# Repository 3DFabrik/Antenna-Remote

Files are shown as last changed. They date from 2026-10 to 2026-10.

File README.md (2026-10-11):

# Antenna Remote

Ein Antennenumschalter für bis zu acht Antennen auf einem ESP32. Er wählt die Antenne nach der Frequenz des Transceivers (Automatik) oder von Hand, zeigt alles auf einem Touch-Display und lässt sich über WLAN, Bluetooth und eine Weboberfläche bedienen. [SDROxide](https://github.com/3DFabrik/sdroxide) kann ihm die Frequenz direkt über WLAN schicken. Die Firmware ist eine Weiterentwicklung der Antenna Remote II.

Gedacht ist die Einheit für die Fernumschalter von [Amplitec](https://www.amplitec.hu/r_sw_3000_4_way_eng.html) (SW:3000) mit vier, sechs oder acht Wegen. Sie schaltet positiv und passt damit zu Umschaltern mit gemeinsamer Masse. Die Anzahl der Antennen (bis zu acht) wird in den Einstellungen gewählt.

Die Firmware-Version steht oben in der Weboberfläche. Ein Release-Build trägt den Tag als Version, ein lokaler Build seine Bauzeit.

## Was dazugehört

- **ESP32** Dev Module, 4 MB Flash. Die Partition `min_spiffs` hält zwei Programme vor, damit ein Update über WLAN möglich ist.
- **Touch-Display** ST7789, 320 × 240, quer eingebaut, mit Touch-Controller.
- **Schieberegister** 74HC164 für die Relais der acht Antennen. Genau ein Ausgang ist aktiv.
- **ICOM-Anschluss** (optional): CI-V an `Serial2` (19200 Baud, GPIO 16 und 17). Der Umschalter liest damit die Frequenz und schaltet auf Wunsch den internen Tuner des Transceivers.

| Funktion | GPIO |
| --- | --- |
| Display MOSI, SCLK, MISO | 4, 18, 19 |
| Display CS, DC, RST | 15, 2, 23 |
| Touch CS | 21 |
| Schieberegister CLR, A/B, CLK | 25, 26, 27 |
| Relais externer Tuner, Relais Tune-Anforderung | 33, 32 |

Die Display-Pins stehen in `libraries/TFT_eSPI/User_Setup.h`. Beim ersten Start fragt das Display nach der Touch-Kalibrierung.

## Bedienung am Gerät

- **Seite 1** zeigt Frequenz, Band und die Antennenliste. `AUTOMATIC MODE` schaltet zwischen Automatik und Handbetrieb um. Zwischen diesem Schalter und `MISC` stehen zwei Symbole für die Verbindung: im Bluetooth-Modus das Bluetooth-Zeichen (grün, solange ein Client verbunden ist), im WLAN-Modus die Signalstärke (drei Bögen) und ein Bildschirm-Symbol, das grün wird, solange SDROxide verbunden ist. Die Weboberfläche zeigt dasselbe oben rechts. Im Handbetrieb wählen UP und DN die Antenne. Hält man `ST` eine Sekunde, wird die aktuelle Antenne für das aktuelle Band gespeichert. Im Automatikmodus heißt dieselbe Taste `TU` und startet den Tuner, siehe unten.
- **Seite 2** (`MISC`) zeigt die Verbindung: Modus, SSID, Status, IP, Signal, ob SDROxide verbunden ist, Antenne und Automatik. Hier wird auch der Verbindungsmodus eingestellt.

## Tuner

In den Einstellungen der Weboberfläche lässt sich pro Antenne das Häkchen `External Tuner` setzen. Ist es für die gewählte Antenne gesetzt, schaltet der Umschalter das erste Relais (GPIO 33) für den externen Tuner. Damit ist der Antennentuner des Transceivers abgeschaltet.

Die Taste `TU` (Display, Automatikmodus) und `TUNING` (Weboberfläche) sind nur dann aktiv, wenn die gewählte Antenne diese Markierung hat. Sonst sind sie grau. Ein Druck löst über das zweite Relais (GPIO 32) für genau fünf Sekunden die Tune-Anforderung aus, auch wenn der Finger auf der Taste bleibt. Der Transceiver sendet dann ein Signal mit geringer Leistung, auf das sich der externe Tuner abstimmt. Während der Anforderung ist die Taste rot. Ein erneuter Druck bricht sie ab, ebenso ein Wechsel der Antenne oder des Modus.

## Verbindung: Bluetooth oder WLAN

Der Umschalter läuft entweder mit Bluetooth oder mit WLAN, nie mit beidem. Auf Seite 2 wechselt `BT -> WLAN` (bzw. `WLAN -> BT`) den Modus. Das Gerät startet danach neu, und der Wechsel muss einmal bestätigt werden.

**WLAN einrichten:** Im WLAN-Modus öffnet `WLAN setup` eine Netzliste mit Scan. Das Netz antippen und das Passwort mit der Bildschirmtastatur eingeben (`Show` zeigt es im Klartext). Versteckte Netze gibt es über `HIDDEN`. Der Status auf Seite 2 nennt Fehler im Klartext, zum Beispiel `SSID not found` oder `Wrong password?`. Das Passwort liegt getrennt von der Konfiguration im Flash und wird nie ausgegeben.

Über die serielle Konsole (115200 Baud) geht es auch:

| Befehl | Wirkung |
| --- | --- |
| `<WIFI,ssid,passwort>` | speichert das WLAN (das Passwort darf Kommas enthalten) |
| `<NETMODE,wifi>` oder `<NETMODE,bt>` | Modus wählen, danach Neustart |
| `<WIFISTATUS>` | Modus, SSID, Status, IP und Signal |

## Weboberfläche

Im WLAN-Modus ist der Umschalter unter `http://<IP-Adresse>/` erreichbar. Die Seite passt sich der Fenstergröße an.

- **Main:** Frequenz in einer LCD-Anzeige, eine Taste pro Antenne, `AUTOMATIC`, `INT TUNER` und `TUNING`.
- **Settings:** Antennenanzahl, Namen, externer Tuner pro Antenne, Zuordnung der Bänder 160 bis 4 m und ICOM-Typ. `Reboot` startet neu. `Reset` stellt die Werkseinstellungen her, behält aber den WLAN-Modus.
- **Update:** Firmware über den Browser einspielen, siehe unten.

Es gibt kein Passwort, der Umschalter gehört ins Heimnetz. Änderungen nimmt er nur per POST mit einem eigenen Header an, damit eine fremde Webseite ihn nicht schalten kann.

## SDROxide

In SDROxide unter Settings → Radio den Haken `Use Antenna Remote` setzen und unter Settings → Servers die IP-Adresse des Umschalters eintragen. SDROxide zeigt dort, ob die Verbindung steht, und schickt die Frequenz des Radios. Die Automatik des Umschalters wählt danach die Antenne.

Das Protokoll ist Text über TCP, Port 4540, eine Zeile pro Befehl. Es kommt immer nur ein Client zum Zug. Ein weiterer wird abgewiesen, solange der erste mindestens einmal in zwei Sekunden fragt. Schweigt er länger, übernimmt ein neuer Client die Verbindung, nach fünf Sekunden Stille wird er getrennt.

| Anfrage | Antwort |
| --- | --- |
| `v` | `AntennaRemote 1` und `RPRT 0` |
| `F <Hz>` | `RPRT 0` (Frequenz des Radios in Hertz) |
| `s` | `ant=<1-8> auto=<0\|1> band=<m> n=<Anzahl> name=<Text>` und `RPRT 0` |
| `M <0\|1>` | `RPRT 0` (Automatik aus oder ein, ab Version 1.1.0) |
| `A <n>` | `RPRT 0` (Antenne `n` wählen und auf Handbetrieb schalten, ab Version 1.2.0) |

Alles andere beantwortet der Umschalter mit `RPRT -1`. SDROxide zeigt die aktive Antenne, einen Schalter für die Automatik und im Handbetrieb Tasten zum Weiterschalten in der Kopfleiste (Box `ANT SW`).

## Windows-Programm

Das Windows-Programm Antenna Remote V2 läuft weiter über Bluetooth oder die serielle Schnittstelle, auch mit OmniRig. Die Befehle in der Form `<ANTNUMBER,3,0>` sind unverändert. Antennen und Bandzuordnung lassen sich jetzt aber auch in der Weboberfläche pflegen.

## Firmware einspielen

Die Release-Dateien stehen unter *Releases*:

- `Antenna-Remote_ota.bin` ist das Programm für das **Update im Browser** (Reiter *Update*) oder per `curl`:
  `curl -H "X-AR: 1" -F "firmware=@Antenna-Remote_ota.bin" http://<IP>/update`
  Das Update läuft nur im WLAN-Modus. Vorher sollte nicht gesendet werden, denn der Umschalter startet danach neu.
  Die Weboberfläche prüft über den Browser (höchstens einmal am Tag) auf GitHub, ob es eine neuere Version gibt, und zeigt dann oben einen Hinweis mit Link zum Reiter *Update*. Dort führt ein Link zu den Dateien des Releases.
- `Antenna-Remote.bin` ist das Abbild für **USB**. Es wird ab Adresse 0 geschrieben:
  `esptool.py --chip esp32 write_flash 0x0 Antenna-Remote.bin`

## Selbst bauen

Arduino IDE oder `arduino-cli` mit dem Board-Paket `esp32:esp32` in Version **2.0.17**. Die mitgelieferte TFT_eSPI passt zu dieser Version, die Core-Reihe 3 baut sie nicht.

```
arduino-cli compile --fqbn esp32:esp32:esp32:PartitionScheme=min_spiffs --libraries libraries .
```

Die Bibliothek `libraries/TFT_eSPI` enthält die Pinbelegung des Displays. Beim Bauen in der Arduino IDE den Ordner `libraries` als Sketchbook-Bibliothek eintragen oder die Bibliothek dorthin kopieren.

## Release über GitHub

Ein Tag `v…` baut die Firmware auf GitHub und legt ein Release mit beiden Dateien an:

```
git tag v1.0.0
git push origin v1.0.0
```

Alternativ startet man *Actions → Release → Run workflow* und gibt die Version ein. Der Ablauf steht in `.github/workflows/release.yml`.

## Hardware

Die Platine liegt unter `hardware/` (KiCad):

- `kicad/` Projekt (Schaltplan, Leiterplatte), Stückliste und Netzliste
- `production/` Gerber- und Bohrdateien, `BOM.xlsx`
- `docs/` Schaltplan als PDF
- `3d/` STEP-Modell

**Bekannte Fehler:**

- Der Buzzer (BZ1) ist im Schaltplan nicht richtig angeschlossen, der ESP32-Pin muss getauscht werden. Die Firmware steuert noch keinen Buzzer an.
- Der Buzzer sitzt auf der Leiterplatte zu nah am Rand und muss etwas weiter nach innen.

## Lizenz

MIT, siehe `LICENSE`. Die Bibliothek TFT_eSPI unter `libraries/TFT_eSPI` hat ihre eigene Lizenz (`license.txt`).

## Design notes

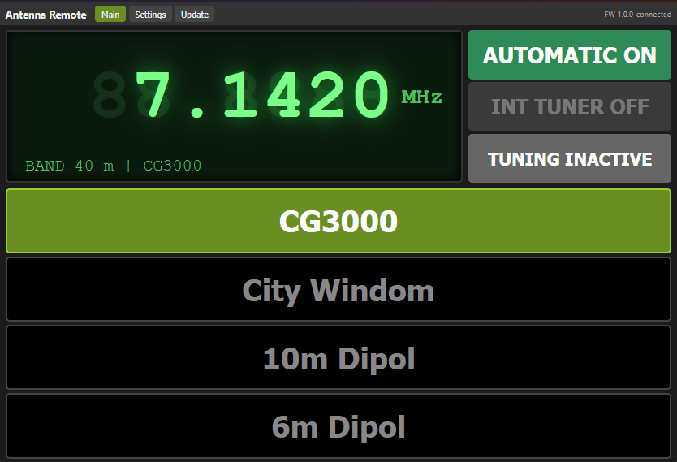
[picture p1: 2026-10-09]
pictures/Web Screenshot.png

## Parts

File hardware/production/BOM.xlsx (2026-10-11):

Source: | U:\Hobby\Funkerei\Antennenumschalter\PCB\Antennenumschalter_ESP32 - V3\Antennenumschalter_ESP32.kicad_sch
Date: | 2023-11-11 14:19
Tool: | Eeschema 7.0.7
Generator: | C:\Program Files\KiCad\7.0\bin\scripting\plugins/bom_csv_grouped_by_value.py
Component Count: | 38
Collated Components:
Item | Qty | Reference(s) | Value | LibPart | Footprint | Datasheet | DNP | Availability | Check_prices | Description | MANUFACTURER | MAXIMUM_PACKAGE_HEIGHT | MF | MP | PARTREV | Package | Price | Purchase-URL | SNAPEDA_PN | STANDARD | Sim.Device | Sim.Pins | SnapEDA_Link
1 | 1 | BZ1 | PB12N23MPW03AQ | Device:Buzzer | Buzzer_Beeper:Buzzer_12x9.5RM7.6 | https://www.reichelt.de/index.html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
2 | 1 | C1 | 330n | Device:C_Polarized | Capacitor_THT:C_Rect_L4.6mm_W2.0mm_P2.50mm_MKS02_FKP02 | ~
3 | 11 | C2, C5, C6, C7, C8, C9, C10, C11, C12, C13, C14 | 22p | Device:C | Capacitor_THT:C_Disc_D5.0mm_W2.5mm_P2.50mm | ~
4 | 1 | C3 | 100n | Device:C | Capacitor_THT:C_Rect_L4.6mm_W2.0mm_P2.50mm_MKS02_FKP02 | ~
5 | 1 | C4 | 100yF/20V | Device:C_Polarized | Capacitor_THT:CP_Radial_D5.0mm_P2.50mm | ~
6 | 1 | D1 | 1N4001 | Device:D | Diode_THT:D_DO-41_SOD81_P3.81mm_Vertical_KathodeUp | ~ |  |  |  |  |  |  |  |  |  |  |  |  |  |  | D | 1=K 2=A
7 | 3 | D2, D3, D4 | 1N4148 | Diode:BA243 | Diode_THT:D_DO-35_SOD27_P7.62mm_Horizontal | https://www.reichelt.de/schalt-diode-100-v-150-ma-do-35-1n-4148-p1730.html?&nbc=1 |  |  |  |  |  |  |  |  |  |  |  |  |  |  | D | 1=K 2=A
8 | 1 | F1 | PTC FRX03060F 300mA | Device:Polyfuse | Fuse:Fuse_BelFuse_0ZRE0005FF_L8.3mm_W3.8mm | https://www.reichelt.de/index.html?ACTION=7&LA=3&OPEN=0&INDEX=0
9 | 1 | J1 | D-SUB BU 09US Female Antenna Switch | Connector:Conn_01x09_Socket | Connector_Dsub:DSUB-9_Female_Horizontal_P2.77x2.84mm_EdgePinOffset7.70mm_Housed_MountingHolesOffset9.12mm | https://www.reichelt.de/index.html?ACTION=446&LA=446&nbc=1&q=d-sub%20bu%2009us
10 | 1 | J3 | D-SUB ST 09US Male Ancillaries | Connector:Conn_01x09_Pin | Connector_Dsub:DSUB-9_Male_Horizontal_P2.77x2.84mm_EdgePinOffset7.70mm_Housed_MountingHolesOffset9.12mm | https://www.reichelt.de/index.html?ACTION=446&LA=446&nbc=1&q=d-sub%20%2009us
11 | 1 | J4 | DISPLAY | Connector:Conn_01x13_Pin | Connector_PinHeader_2.54mm:PinHeader_1x13_P2.54mm_Vertical | ~
12 | 2 | K1, K2 | CO 3570.1210.121 | Relay:DIPxx-1Axx-11x | Relay_THT:COMUS Reed-Relais 12 V DC, 10 W - 1 NO | https://www.reichelt.de/reed-relais-12-v-dc-10-w-1-no-co-3570-1210-121-p340168.html?&nbc=1
13 | 2 | Q1, Q2 | BC550 | Transistor_BJT:BC550 | Package_TO_SOT_THT:TO-92L_Inline_Wide | https://www.onsemi.com/pub/Collateral/BC550-D.pdf
14 | 2 | R1, R7 | 10K | Device:R | Resistor_THT:R_Axial_DIN0207_L6.3mm_D2.5mm_P10.16mm_Horizontal | ~
15 | 3 | R2, R3, R6 | 4K7 | Device:R | Resistor_THT:R_Axial_DIN0207_L6.3mm_D2.5mm_P10.16mm_Horizontal | ~
16 | 2 | R4, R5 | 100K | Device:R | Resistor_THT:R_Axial_DIN0207_L6.3mm_D2.5mm_P10.16mm_Horizontal | ~
17 | 1 | U1 | 74HC164 | 74xx:74HC164 | Package_DIP:DIP-14_W7.62mm_Socket | https://www.reichelt.de/schieberegister-8-bit-seriell-zu-parallel-2--6-v-dil-14-74hc-164-p3154.html?nbc=1
18 | 1 | U2 | LM7805_TO220 | Regulator_Linear:LM7805_TO220 | Package_TO_SOT_THT:TO-220-3_Vertical | https://www.onsemi.cn/PowerSolutions/document/MC7800-D.PDF
19 | 1 | U3 | ULN2803A | Transistor_Array:TBD62783A | Package_DIP:DIP-18_W7.62mm_Socket | https://www.reichelt.de/eight-darlington-arrays-dil-18-uln-2803a-p22085.html?&nbc=1
20 | 1 | U4 | ESP32-DEVKITC-32D | ESP32-DEVKITC-32D:ESP32-DEVKITC-32D | esp32_DevKitC:MODULE_ESP32-DEVKITC-32D |  |  | In Stock | https://www.snapeda.com/parts/ESP32-DEVKITC-32D/Espressif+Systems/view-part/?ref=eda | WiFi Development Tools (802.11) ESP32 General Development Kit, ESP32-WROOM-32D on the board | Espressif Systems | N/A | Espressif Systems | ESP32-DEVKITC-32D | V4 | None | None | https://www.snapeda.com/api/url_track_click_mouser/?unipart_id=2777395&manufacturer=Espressif Systems&part_name=ESP32-DEVKITC-32D&search_term=None | ESP32-DEVKITC-32D | Manufacturer Recommendations |  |  | https://www.snapeda.com/parts/ESP32-DEVKITC-32D/Espressif+Systems/view-part/?ref=snap

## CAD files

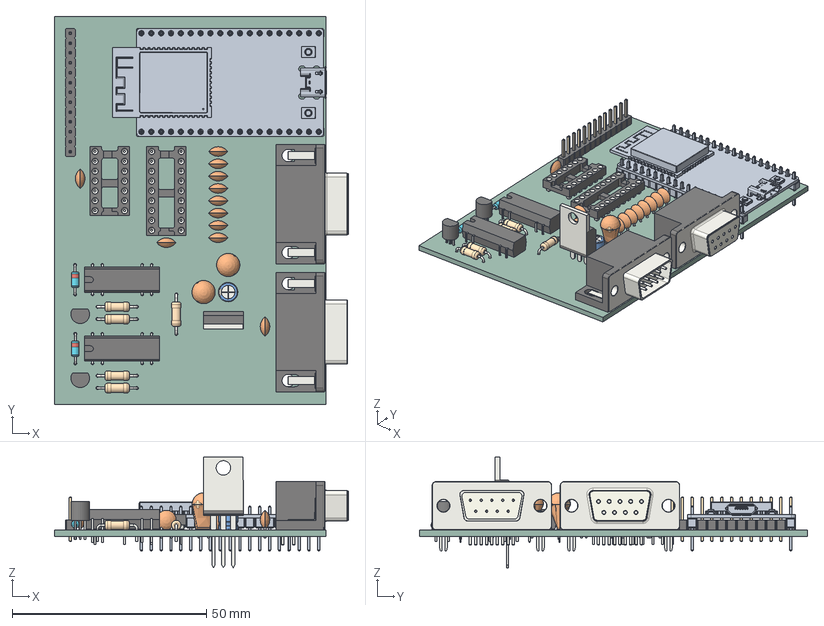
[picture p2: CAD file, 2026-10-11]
hardware/3d/Antenna-Remote.step
75.8 x 100.0 x 28.5 mm
Antenna-Remote PCB

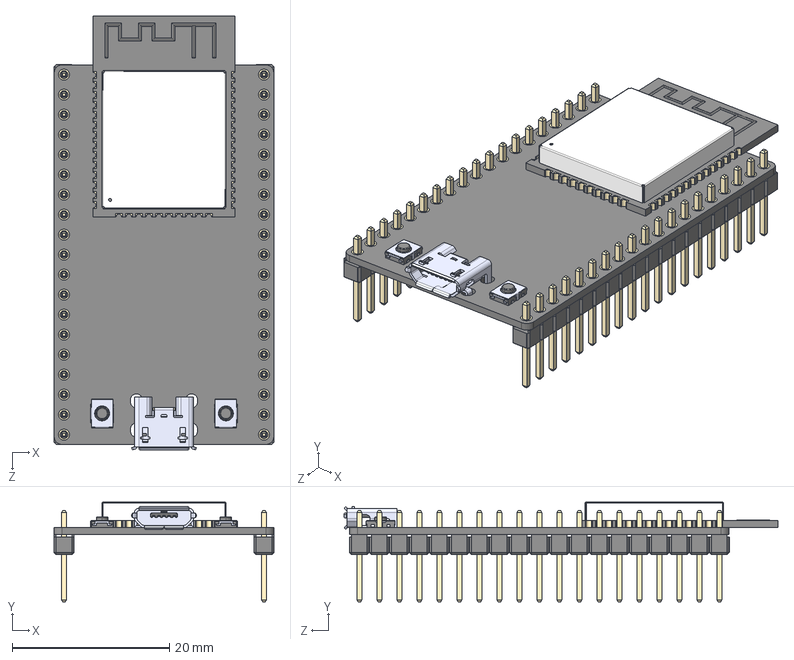
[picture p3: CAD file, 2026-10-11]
hardware/parts/esp32_DevKitC/ESP32-DEVKITC-32D.step
27.9 x 12.7 x 55.1 mm
board
header x 2
ESP32-WROOM-32D
micro usb
button x 2

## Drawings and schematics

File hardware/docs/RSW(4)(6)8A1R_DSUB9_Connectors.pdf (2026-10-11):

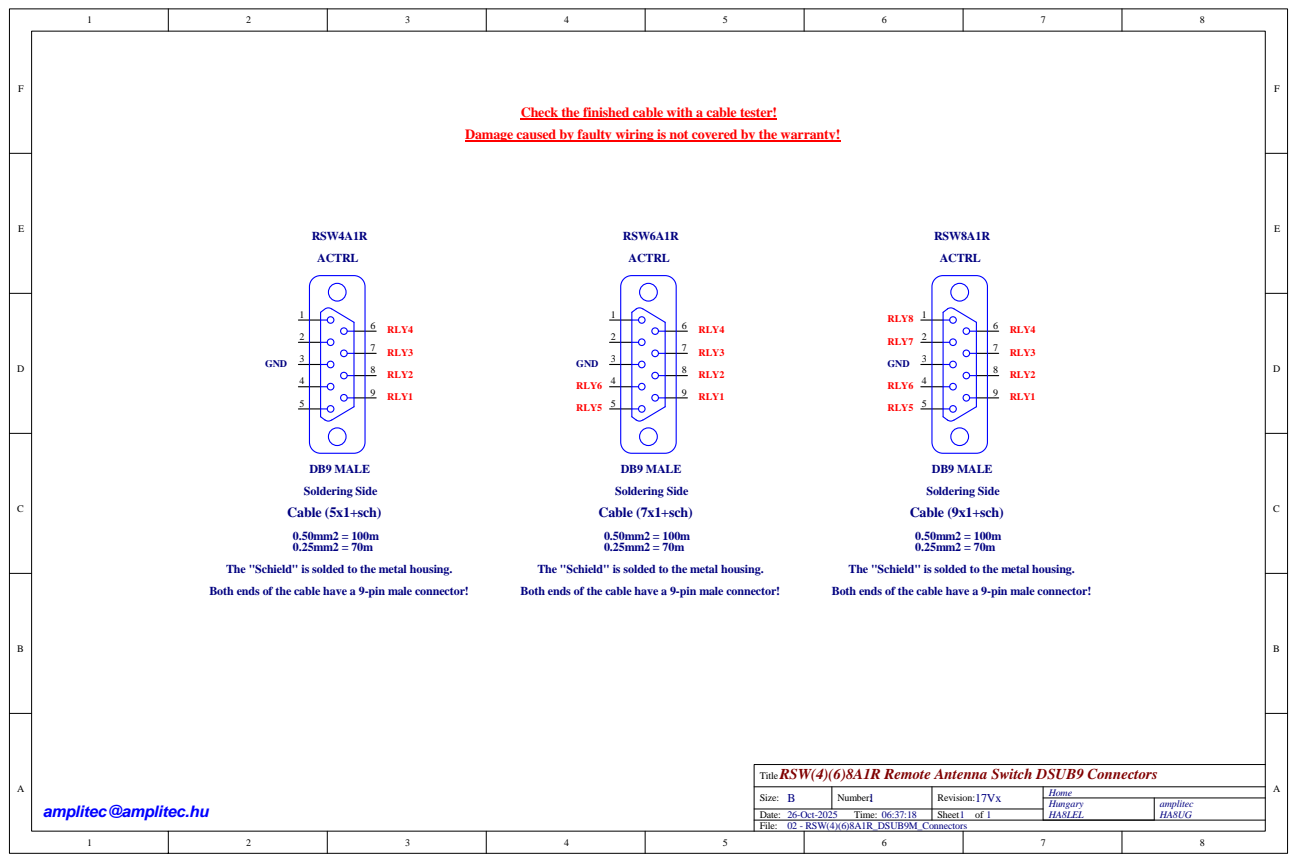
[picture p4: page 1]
Home Hungary HA8LEL; amplitec; 26-Oct-2025; Size:; Number:; Revision:; Time:; Sheet; ACTRL; DB9 MALE; RLY3; GND; RLY2; RLY1; RLY4; Soldering Side; RSW4A1R; Cable (5x1+sch); RLY5; RLY6; RSW6A1R; Cable (7x1+sch); RLY8; RLY7; RSW8A1R; Cable (9x1+sch); Both ends of the cable have a 9-pin male connector!

Check the finished cable with a cable tester!

Damage caused by faulty wiring is not covered by the warranty!

The "Schield" is solded to the metal housing.

RSW(4)(6)8A1R Remote Antenna Switch DSUB9 Connectors
Title
Date:
02 - RSW(4)(6)8A1R_DSUB9M_Connectors
File:

amplitec@amplitec.hu

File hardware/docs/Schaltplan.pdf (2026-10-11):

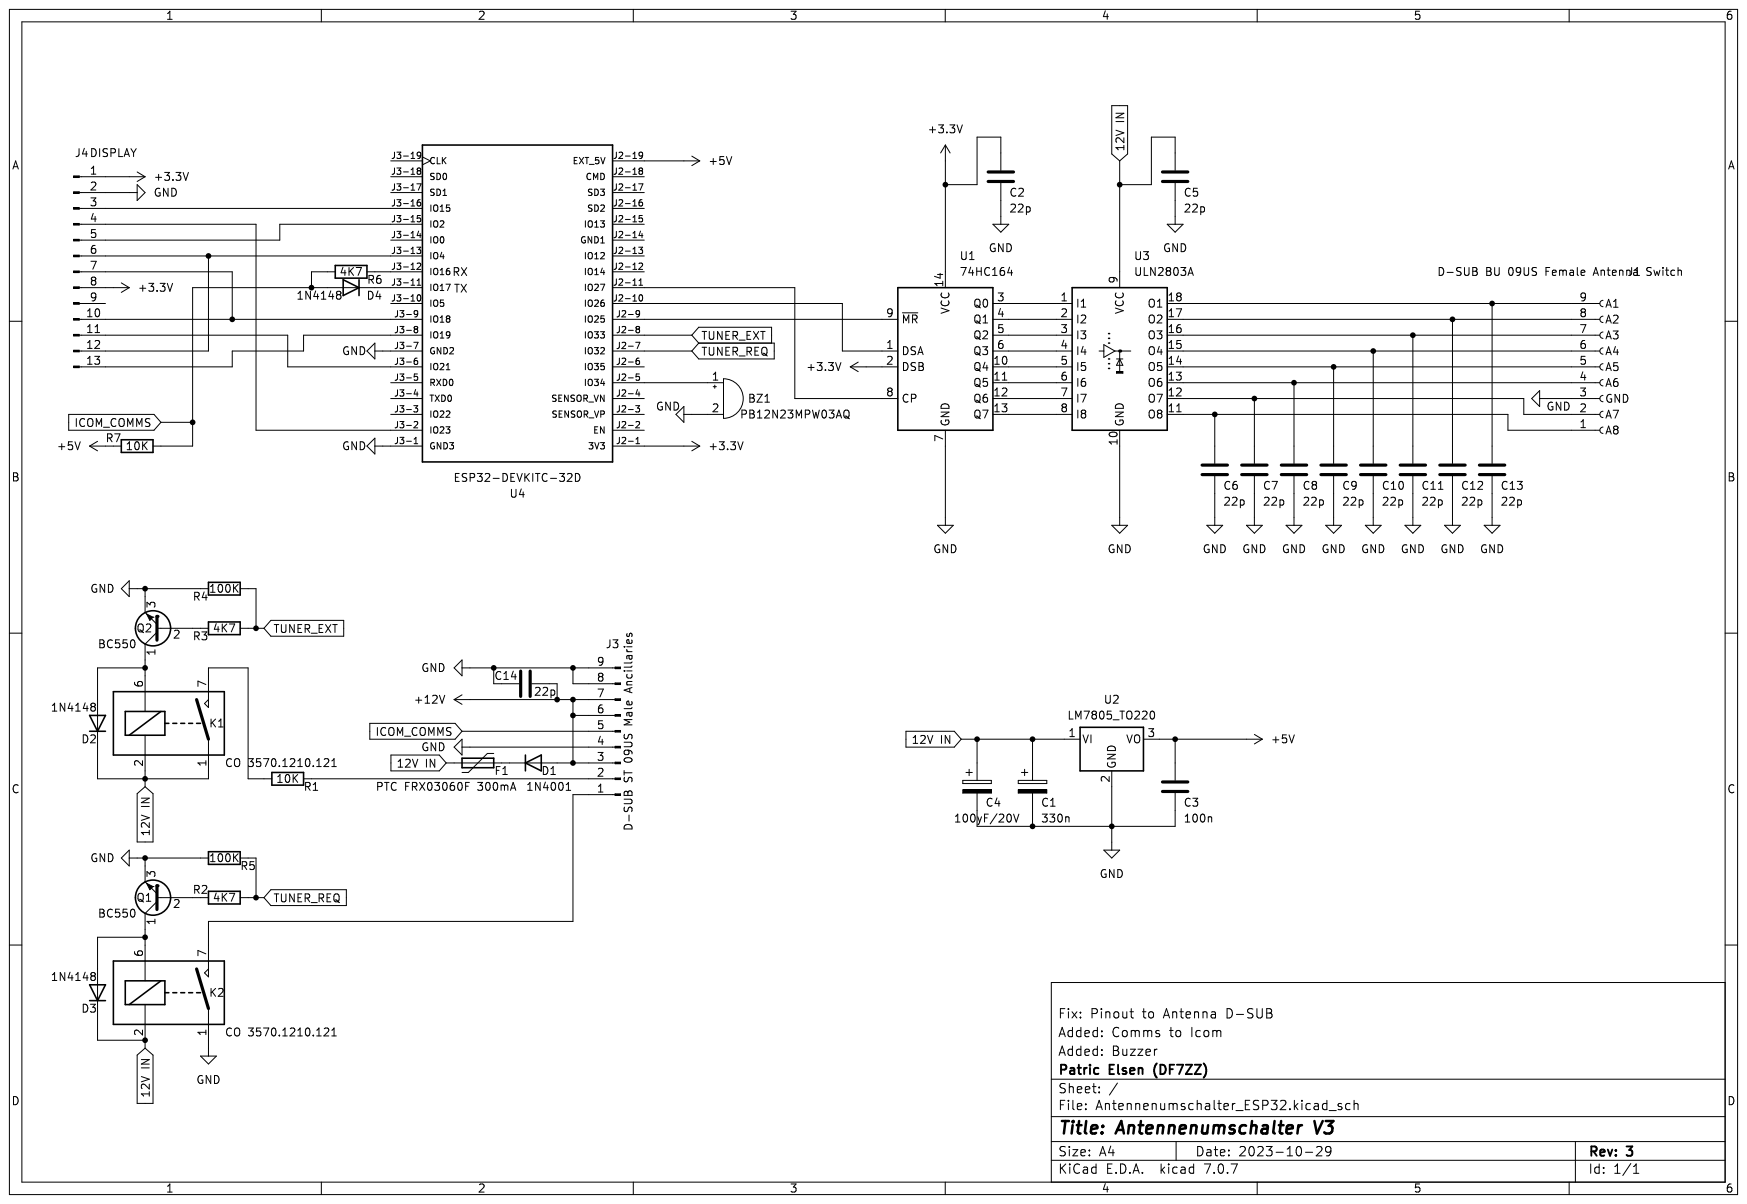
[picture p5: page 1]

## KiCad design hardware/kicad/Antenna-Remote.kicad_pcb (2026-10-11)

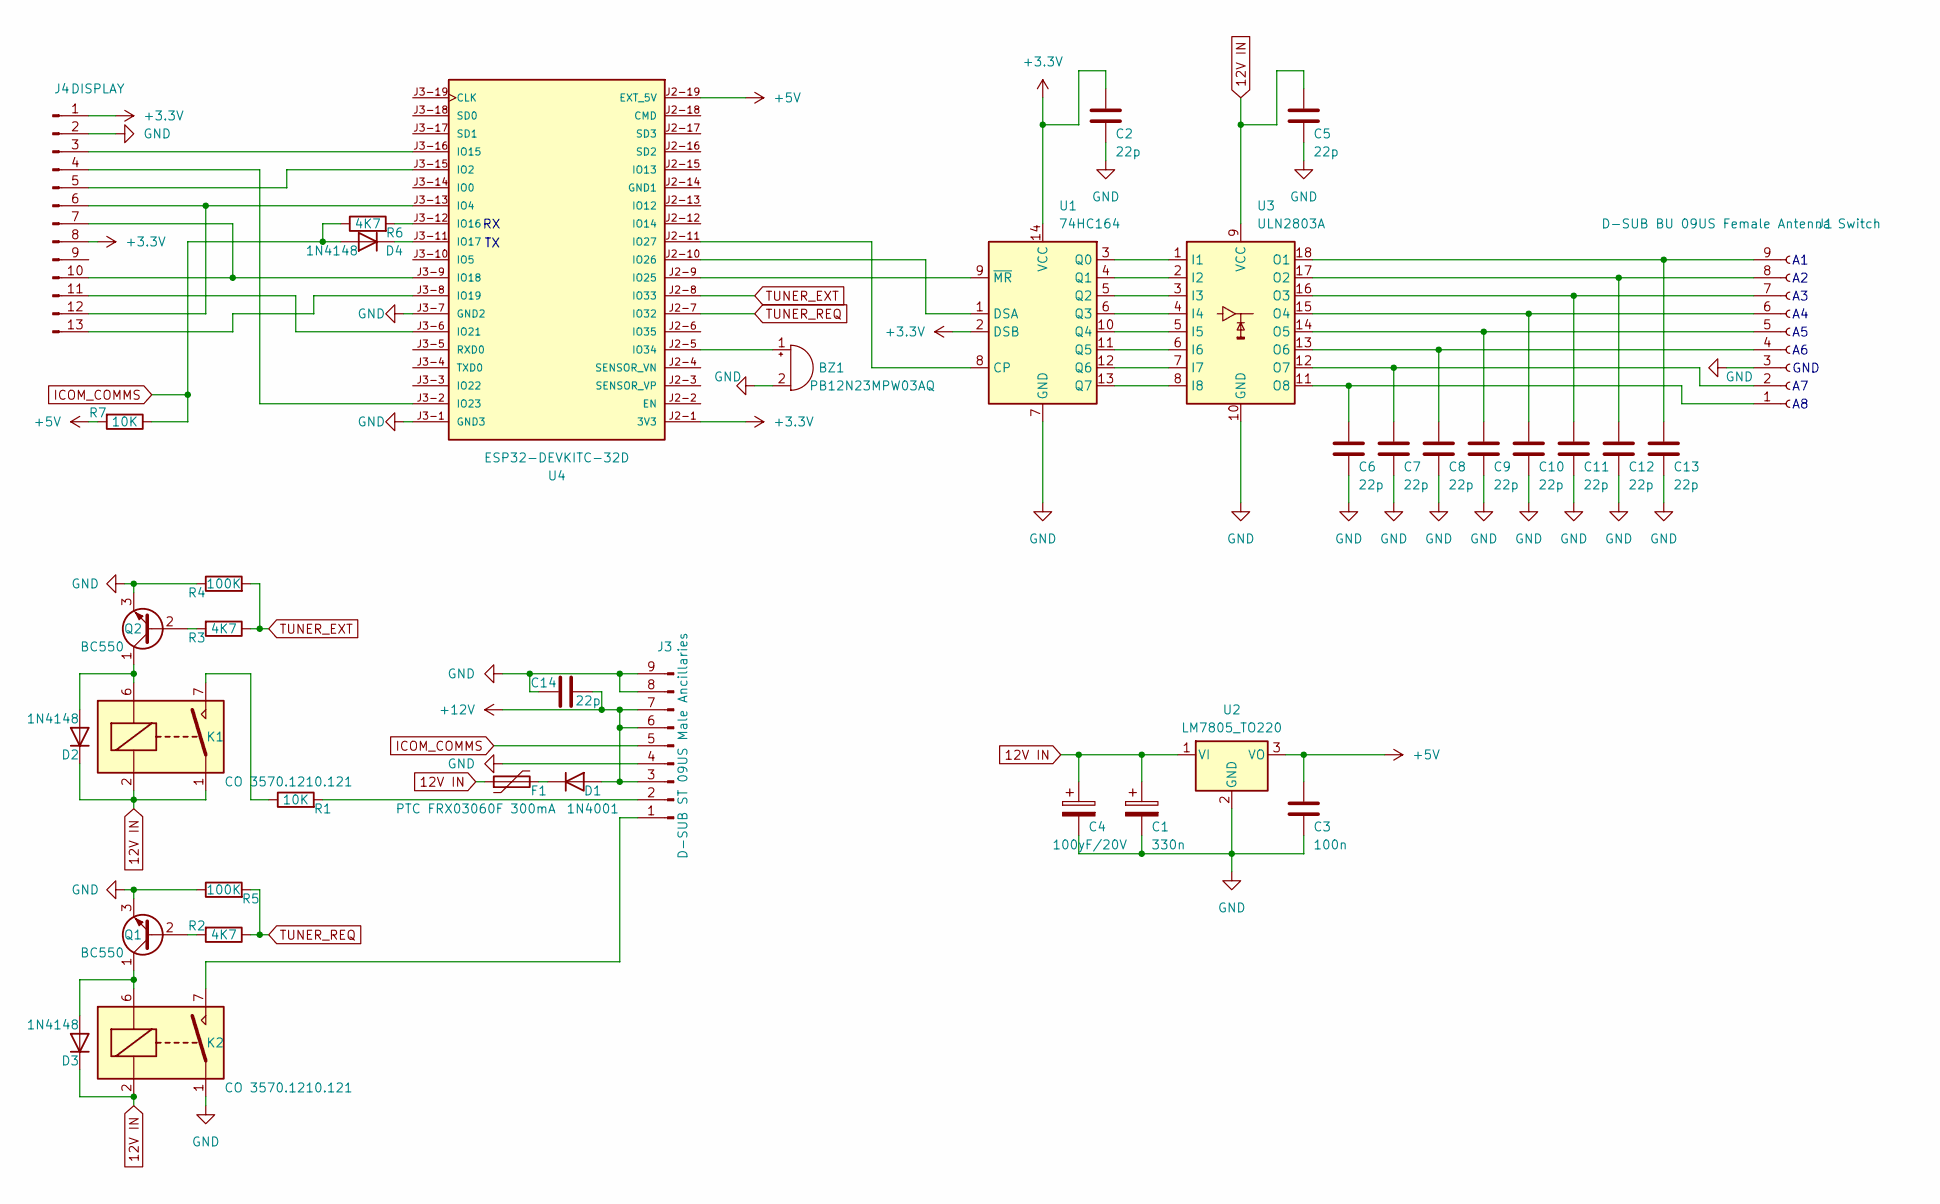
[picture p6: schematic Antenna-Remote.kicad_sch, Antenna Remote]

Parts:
BZ1: PB12N23MPW03AQ; Buzzer_12x9.5RM7.6
C1: 330n; C_Rect_L4.6mm_W2.0mm_P2.50mm_MKS02_FKP02
C2, C5, C6, C7, C8, C9, C10, C11, C12, C13, C14: 22p; C_Disc_D5.0mm_W2.5mm_P2.50mm
C3: 100n; C_Rect_L4.6mm_W2.0mm_P2.50mm_MKS02_FKP02
C4: 100yF/20V; CP_Radial_D5.0mm_P2.50mm
D1: 1N4001; D_DO-41_SOD81_P3.81mm_Vertical_KathodeUp
D2, D3, D4: 1N4148; D_DO-35_SOD27_P7.62mm_Horizontal
F1: PTC FRX03060F 300mA; Fuse_BelFuse_0ZRE0005FF_L8.3mm_W3.8mm
J1: D-SUB BU 09US Female Antenna Switch; DSUB-9_Female_Horizontal_P2.77x2.84mm_EdgePinOffset7.70mm_H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
J3: D-SUB ST 09US Male Ancillaries; DSUB-9_Male_Horizontal_P2.77x2.84mm_EdgePinOffset7.70mm_Hou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
J4: DISPLAY; PinHeader_1x13_P2.54mm_Vertical
K1, K2: CO 3570.1210.121; COMUS Reed-Relais 12 V DC, 10 W - 1 NO
Q1, Q2: BC550; TO-92L_Inline_Wide
R1, R7: 10K; R_Axial_DIN0207_L6.3mm_D2.5mm_P10.16mm_Horizontal
R2, R3, R6: 4K7; R_Axial_DIN0207_L6.3mm_D2.5mm_P10.16mm_Horizontal
R4, R5: 100K; R_Axial_DIN0207_L6.3mm_D2.5mm_P10.16mm_Horizontal
U1: 74HC164; DIP-14_W7.62mm_Socket
U2: LM7805_TO220; TO-220-3_Vertical
U3: ULN2803A; DIP-18_W7.62mm_Socket
U4: ESP32-DEVKITC-32D; MODULE_ESP32-DEVKITC-32D; PARTREV V4

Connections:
12V IN: C1.1, C4.1, C5.1, D2.1 (K), D3.1 (K), F1.1, K1.1, K1.2, K1.14, K2.2, U2.1 (VI), U3.9 (VCC)
+3.3V: C2.1, J4.1 (VCC), J4.8 (LED), U1.2 (DSB), U1.14 (VCC), U4.J2-1 (3V3)
+5V: C3.1, R7.2, U2.3 (VO), U4.J2-19 (EXT_5V)
+12V: C14.1, D1.2 (A), J3.3, J3.6, J3.7
GND: BZ1.2 (+), C1.2, C2.2, C3.2, C4.2, C5.2, C6.2, C7.2, C8.2, C9.2, C10.2, C11.2, C12.2, C13.2, C14.2, J1.3, J3.4, J3.8, J3.9, J4.2 (GND), K2.1, K2.14, Q1.3 (E), Q2.3 (E), R4.1, R5.1, U1.7 (GND), U2.2 (GND), U3.10 (GND), U4.J3-1 (GND3), U4.J3-7 (GND2)
ICOM_COMMS: D4.2 (A), J3.5, R6.1, R7.1
unnamed: BZ1.1 (-), U4.J2-5 (IO34)
unnamed: D1.1 (K), F1.2
unnamed: D2.2 (A), K1.6, Q2.1 (C)
unnamed: D3.2 (A), K2.6, Q1.1 (C)
unnamed: D4.1 (K), U4.J3-11 (IO17)
unnamed: C6.1, J1.1, U3.11 (O8)
unnamed: C7.1, J1.2, U3.12 (O7)
unnamed: C8.1, J1.4, U3.13 (O6)
unnamed: C9.1, J1.5, U3.14 (O5)
unnamed: C10.1, J1.6, U3.15 (O4)
unnamed: C11.1, J1.7, U3.16 (O3)
unnamed: C12.1, J1.8, U3.17 (O2)
unnamed: C13.1, J1.9, U3.18 (O1)
unnamed: J3.1, K2.7, K2.8
unnamed: J3.2, R1.2
unnamed: J4.3, U4.J3-16 (IO15)
unnamed: J4.4, U4.J3-2 (IO23)
unnamed: J4.5, U4.J3-15 (IO2)
unnamed: J4.7, J4.10, U4.J3-9 (IO18)
unnamed: J4.11, U4.J3-6 (IO21)
unnamed: J4.6, J4.12, U4.J3-13 (IO4)
unnamed: J4.13, U4.J3-8 (IO19)
unnamed: K1.7, K1.8, R1.1
unnamed: Q1.2 (B), R2.2
unnamed: Q2.2 (B), R3.2
unnamed: U1.8 (CP), U4.J2-11 (IO27)
unnamed: U1.1 (DSA), U4.J2-10 (IO26)
unnamed: U1.3 (Q0), U3.1 (I1)
unnamed: U1.4 (Q1), U3.2 (I2)
unnamed: U1.5 (Q2), U3.3 (I3)
unnamed: U1.6 (Q3), U3.4 (I4)
unnamed: U1.10 (Q4), U3.5 (I5)
unnamed: U1.11 (Q5), U3.6 (I6)
unnamed: U1.12 (Q6), U3.7 (I7)
unnamed: U1.13 (Q7), U3.8 (I8)
unnamed: U1.9 (~MR), U4.J2-9 (IO25)
unnamed: R6.2, U4.J3-12 (IO16)
TUNER_EXT: R3.1, R4.2, U4.J2-8 (IO33)
TUNER_REQ: R2.1, R5.2, U4.J2-7 (IO32)

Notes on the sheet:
GND

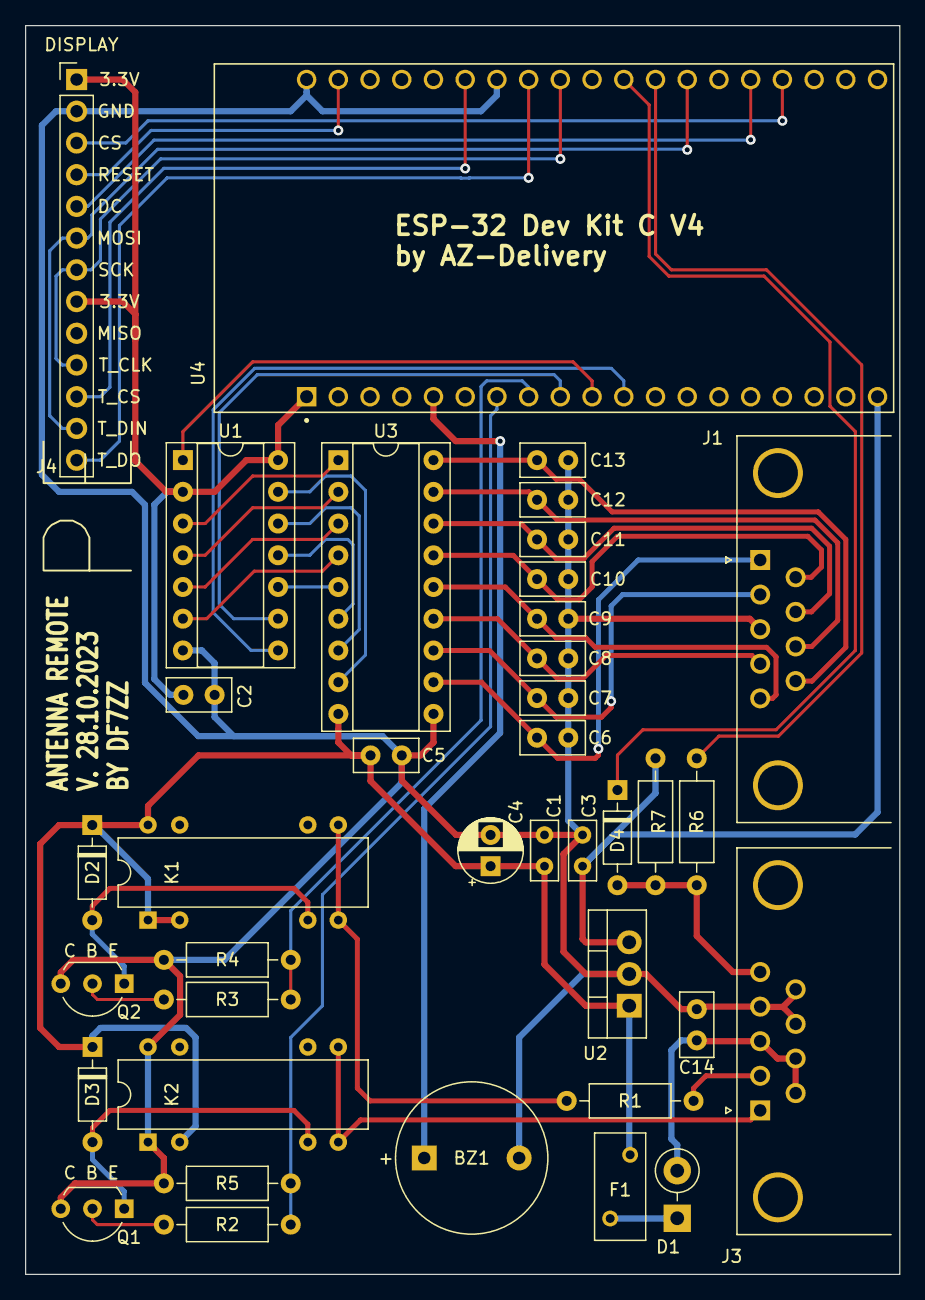
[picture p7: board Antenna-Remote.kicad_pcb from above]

Board: 2 copper layers, 70.0 x 100.0 mm, 38 parts (0 on the bottom side), 45 nets.

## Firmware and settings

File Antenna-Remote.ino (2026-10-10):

#include "FS.h"
#include "SPIFFS.h"
#include <WiFi.h>
#include <WiFiClient.h>
#include <WiFiServer.h>
#include <Preferences.h>
#include <Update.h>
Preferences netPrefs;  // WLAN credentials live here, not in config.txt, so "sendconfig" never reveals them
#include "BluetoothSerial.h"
BluetoothSerial SerialBT;
#include <WebServer.h>
#include "index.h"  //Web page header file
WebServer server(80);

#include <TFT_eSPI.h>  // Graphics and font library for ST7789 driver chip, be careful with updating as the fucking update will delete your pin-settings
#include <SPI.h>

#define TFT_GREY 0x5AEB  // New colours....
#define TFT_POPPY 0XD208
#define TFT_MINTGR 0XEFFF
#define TFT_NPBLUE 0X9EDB
#define TFT_UCLABLUE 0X43B3
#define TFT_DELFTBLUE 0X198A

int COLOR_BG = TFT_BLACK;
int COLOR_HIGHLIGHT = TFT_POPPY;

TFT_eSPI tft = TFT_eSPI();  // Invoke library
TFT_eSprite img = TFT_eSprite(&tft);

// Touch business
#define CALIBRATION_FILE "/TouchCalData1"
#define REPEAT_CAL false
#define KEY_X 295  // Center of key
#define AUTO_CX 98  // The AUTOMATIC button runs from the left edge to x = 196; the link icons sit between it and MISC
#define AUTO_W 196
#define NUM_KEYS 7
String b0_txt = "UP";
String b1_txt = "ST";
String b2_txt = "DN";
String b3_p1_txt = "MISC";
String b3_p2_txt = "BACK";
String b4_txt = "AUTOMATIC MODE OFF";
String b5_txt = "WLAN setup";
String b7_txt_off = "BT -> WLAN";  // shown while in Bluetooth mode: what the button switches to
String b7_txt_on = "WLAN -> BT";
int n_presscount_b1 = 0;
TFT_eSPI_Button key[NUM_KEYS];
unsigned long previousMillis = 0;  // will store last time touchscreen was checked
const long buttonIntervall = 100;

// Connection: either Bluetooth or WLAN, chosen at boot (config key b_wifi_on). Both radios at once do not fit.
bool b_wifi_on = false;  // true = WLAN mode, false = Bluetooth mode
bool bt_active = false;
String wifi_ssid = "";
String wifi_pass = "";
volatile int wifi_reason = 0;  // last disconnect reason from the WiFi stack, 0 = none
bool wifi_hold = false;        // true while the setup pages scan, so the retry timer stays out of the way
bool wifi_was_conn = false;
unsigned long wifi_last_try = 0;
bool servers_started = false;
unsigned long modeConfirmUntil = 0;
unsigned long hintUntil = 0;
String hintText = "";

// Remote protocol "AntennaRemote 1" for SDROxide: text lines on TCP, see crates/sdroxide-types/src/antremote.rs
const uint16_t RIG_PORT = 4540;
const unsigned long RIG_IDLE_MS = 5000;  // SDROxide polls once a second; silence this long means the client is gone
const unsigned long RIG_REPLACE_MS = 2000;  // a newcomer takes over from a client quiet for this long
WiFiServer rigServer(RIG_PORT);
WiFiClient rigClient;
String rigLine = "";
unsigned long rigLastSeen = 0;

// Firmware update over WLAN (POST /update, from the Update tab of the web page)
// Set by the release build (-DFW_VERSION="v1.2.3"); a local build shows its build time.
#ifndef FW_VERSION
#define FW_VERSION __DATE__ " " __TIME__
#endif
const char fwVersion[] = FW_VERSION;
bool otaBusy = false;  // from the first byte of an upload: the loop does nothing but serve it
bool otaBeginOk = false;
bool otaOk = false;
bool otaUploadStarted = false;
bool otaDenied = false;
unsigned long otaWifiLostAt = 0;
int otaPct = -1;
String otaErr = "";

// Setup pages (3 = network list, 4 = keyboard)
struct UiBtn {
  int16_t x, y, w, h;
  const char* label;
};
struct KbKey {
  int16_t x, y, w, h;
  char label[8];
  int16_t code;  // ASCII, or one of the KC_ values
};
const int KC_SHIFT = -1, KC_DEL = -2, KC_SYM = -3, KC_SHOW = -4, KC_CANCEL = -5, KC_OK = -6;
const int MAX_NETS = 16;
String netSsid[MAX_NETS];
int netRssi[MAX_NETS];
bool netOpen[MAX_NETS];
int netCount = 0;
int netTop = 0;
String pendingSsid = "";
String kbText = "";
int kbTarget = 1;  // 0 = SSID, 1 = password
int kbLayout = 0;  // 0 = letters, 2 = symbols
bool kbShift = false;
bool kbShow = false;
bool setupTouchWas = true;
String p2Last[8];

// Serial receive business
int icom_use = 0;        // sett to 1 in case you want tp use the icom CIV function of the TRX
byte TRX_address(0x98);  // HEX 0x70/112 = Icom IC-7000, 0x94/148 = Icom IC-7300, 0x98/152 = Icom IC-7610, store in SPIFFS as decimal value
const byte numChars = 128;  // a WLAN password can be 63 characters
char receivedChars[numChars];
char tempChars[numChars];         // temporary array for use when parsing
char SRX_TYPE[numChars] = { 0 };  // variables to hold the parsed data
float RX_FREQ = 0.0;
boolean newData = false;

// Misc Variabel
float QRG = 0;
int QRG_len_old = 0;
int BAND = 0;
int BAND_len_old = 0;
String ANT = "";
String ANT_OLD = "";
bool b_automatic = false;
bool b_booting = true;

//Define Bands:
int l160 = 1810;
int h160 = 2000;
int l80 = 3500;
int h80 = 3800;
int l60 = 5250;
int h60 = 5450;
int l40 = 7000;
int h40 = 7200;
int l30 = 10100;
int h30 = 10150;
int l20 = 14000;
int h20 = 14350;
int l17 = 18068;
int h17 = 18168;
int l15 = 21000;
int h15 = 21450;
int l12 = 24890;
int h12 = 24990;
int l10 = 28000;
int h10 = 29700;
int l6 = 50000;
int h6 = 52000;
int l4 = 70150;
int h4 = 70200;

//Define Antennas
String A1NAME = "1";  // Antenna names (Will be overwritten by what is found in SPIFFS config.txt)
String A2NAME = "2";  // ...
String A3NAME = "3";  // ..
String A4NAME = "4";  // .
String A5NAME = "5";
String A6NAME = "6";
String A7NAME = "7";
String A8NAME = "8";

String TUNEROFF = "0";  // Holds a decimal converted 8 bit binary which represents the use of the external tuner for each antenna
bool A1EXTT = 0;        // if bit is set this antenna uses an external tuner
bool A2EXTT = 0;        // ...
bool A3EXTT = 0;        // ..
bool A4EXTT = 0;        // .
bool A5EXTT = 0;
bool A6EXTT = 0;
bool A7EXTT = 0;
bool A8EXTT = 0;

//Define Antenna 2 Band
int a160m = 1;
int a80m = 1;
int a60m = 1;
int a40m = 1;
int a30m = 1;
int a20m = 1;
int a17m = 1;
int a15m = 1;
int a12m = 1;
int a10m = 1;
int a6m = 1;
int a4m = 1;

// The same settings as tables, for the web interface
String* antNames[8] = { &A1NAME, &A2NAME, &A3NAME, &A4NAME, &A5NAME, &A6NAME, &A7NAME, &A8NAME };
int* bandAnt[12] = { &a160m, &a80m, &a60m, &a40m, &a30m, &a20m, &a17m, &a15m, &a12m, &a10m, &a6m, &a4m };
const char* BAND_KEY[12] = { "a160m", "a80m", "a60m", "a40m", "a30m", "a20m", "a17m", "a15m", "a12m", "a10m", "a6m", "a4m" };
const int BAND_M[12] = { 160, 80, 60, 40, 30, 20, 17, 15, 12, 10, 6, 4 };

int antenna_selected = 1;  // the currently selected antenna number (1-n_ant_max)
int n_ant_max = 8;         // amount of antennas the switch can handle
int n_disp_page_old = 0;   // total amount of available display pages
int n_disp_page = 1;       // currently selected display page

// alive message
unsigned long aliveMillis = 0;
const long aliveintervall = 1000;  // intervall time in which a status-String gets send
String alivemsg = "";              // contains the alive message

// Scrolltext
unsigned long anttxtMillis = 0;
const long anttxtintervall = 35;
int textboxdiffy = 45;
int textboxstartfromtop = 10;
int scrolltarget = 0;
int scrollposact = 0;
//bool b_ant_col = true;

// Shift Register Pins
const int CLR_pin = 25;  // CLR-Pin of the 74HC164
const int AB_pin = 26;   // Input pin A or B of the 74HC164, remember to put 2nd open input to VCC
const int CLK_pin = 27;  // CLK-Pin of the 74HC164

// ICOM Tuner relais pins
const int TUNE_EXT_pin = 33;
const int TUNE_REQ_pin = 32;
bool tuning = false;
unsigned long tuneStart = 0;
const unsigned long TUNE_MS = 5000;  // a tune request is latched this long, then dropped
bool tuner = false;
int antenna_driven = 0;  // antenna the shift register currently holds

// ICOM coms variables
const byte startMarker = 0xFE;  // Indicates where the icom signal string starts
const byte endMarker = 0xFD;    // Indicates where the icom signal string ends
const int maxDataLength = 16;
byte receivedData[maxDataLength];  // Array for the recieved data bytes
int dataIndex = 0;                 // Pointer into the data array
bool newData2 = false;             // Set to true when a new data-array has been received
float SValue_raw = 0;
float SValue = 0;


//  ************************************************** Setup *******************************************************************************
void setup(void) {
  // Shift register pins:
  pinMode(AB_pin, OUTPUT);
  pinMode(CLK_pin, OUTPUT);
  pinMode(CLR_pin, OUTPUT);
  pinMode(TUNE_EXT_pin, OUTPUT);
  pinMode(TUNE_REQ_pin, OUTPUT);

  Serial.begin(115200);  // Serial console
  Serial2.begin(19200);  // ICOM CI-V
  Serial.println("Booting Sketch...");

  tft.init();
  tft.setRotation(3);
  tft.fillScreen(COLOR_BG);
  touch_calibrate();
  tft.setTextColor(TFT_GOLD);
  tft.setCursor(0, 0);
  tft.println("Booting");
  img.createSprite(260, 130);
  // Here we try to get some variables out of the software:
  tft.println("Reading Config values");
  readConfig();

  loadWifiCreds();
  if (b_wifi_on) {
    tft.println("Mode: WLAN");
    startWifi();  // connects in the background; the loop brings the servers up
  } else {
    tft.println("Mode: Bluetooth");
    SerialBT.begin("AntennaRemote");  //Name des ESP32
    bt_active = true;
    Serial.println("Bluetooth ready to connect");
  }

  tft.println("Selecting Antennas");
  sel_antenna();

  tft.println("Starting Display");
  tft_update();
  b_booting = false;
}

// *************************************************** LOOP ********************************************************************************
void loop(void) {

  if (otaBusy) {  // an update is coming in: nothing else may take heap, time or the relays
    if (WiFi.status() != WL_CONNECTED) {
      if (!otaWifiLostAt) otaWifiLostAt = millis();
      else if (millis() - otaWifiLostAt > 8000) ESP.restart();
    } else {
      otaWifiLostAt = 0;
    }
    server.handleClient();
    if (otaUploadStarted && !otaOk && otaErr.length()) {
      otaFailScreen(otaErr);
      delay(2000);
      ESP.restart();
    }
    yield();
    return;
  }


  recvWithStartEndMarkers();
  if (newData == true) {
    strcpy(tempChars, receivedChars);
    parseData();
    //showParsedData();
    newData = false;
  }

  if ((WiFi.status() == WL_CONNECTED) && (b_wifi_on)) {  // Only serve in case we are connected to the network
    server.handleClient();
    rigPoll();
  }
  wifiTick();

  if (tuning && millis() - tuneStart >= TUNE_MS) setTuning(false);

  if (TRX_address >= 1) geticomdata();
  if (newData2) {
    // Neue Daten verarbeiten oder anzeigen
    float QRGreaded = processReceivedData();
    if (QRGreaded > 0)  // new QRG
    {
      QRG = QRGreaded;
      tft_update();
    }
    // Zurücksetzen für den nächsten Durchlauf
    newData2 = false;
  }


  if (millis() - anttxtMillis >= anttxtintervall) {
    anttxtMillis = millis();
    if (n_disp_page == 1) { scrollAntennas(); }
  }

  //Touchscreen Business
  if (millis() - previousMillis >= (n_disp_page >= 3 ? 30UL : (unsigned long)buttonIntervall)) {  // the keyboard needs quicker polling than the buttons
    previousMillis = millis();
    uint16_t t_x = 0, t_y = 0;                // To store the touch coordinates
    bool pressed = tft.getTouch(&t_x, &t_y);  // Get current touch state and coordinates
    for (uint8_t b = 0; b < NUM_KEYS; b++) {  // Adjust press state of each key appropriately
      if (pressed && key[b].contains(t_x, t_y))
        key[b].press(true);  // tell the button it is pressed
      else
        key[b].press(false);  // tell the button it is NOT pressed
    }

    if (n_disp_page >= 3) { setupTouch(pressed, t_x, t_y); }

    if (n_disp_page == 1) {  // Check if any key has changed state
      if (b_automatic == false) {
        tft.setTextFont(4);
        if (key[0].justPressed()) {  // UP Button
          key[0].drawButton(true, b0_txt);
          if (antenna_selected <= (n_ant_max - 1)) {
            antenna_selected++;
            sel_antenna();
          }
        }
        if (key[0].justReleased()) { key[0].drawButton(false, b0_txt); }

        if (key[1].isPressed()) {
          n_presscount_b1++;
          if (n_presscount_b1 == 10) {
            writeConfig("a" + String(BAND) + "m=" + String(antenna_selected));                   // Write Band to antenna to SPIFFS
            key[1].initButton(&tft, KEY_X, 75, 50, 50, TFT_WHITE, TFT_GREEN, TFT_WHITE, "", 1);  // ST Button
            key[1].drawButton(false, b1_txt);
          }
        }
        if (key[1].justPressed()) {  // ST Button
          key[1].drawButton(true, b1_txt);
        }
        if (key[1].justReleased()) {
          key[1].initButton(&tft, KEY_X, 75, 50, 50, TFT_WHITE, COLOR_BG, TFT_WHITE, "", 1);  // ST Button
          key[1].drawButton(false, b1_txt);
          n_presscount_b1 = 0;
        }

        if (key[2].justPressed()) {  // DN Button
          key[2].drawButton(true, b2_txt);
          if (antenna_selected >= 2) {
            antenna_selected--;
            sel_antenna();
          }
        }
        if (key[2].justReleased()) { key[2].drawButton(false, b2_txt); }
      } else {
        tft.setTextFont(4);
        if (key[1].justPressed() && digitalRead(TUNE_EXT_pin)) setTuning(!tuning);  // TU Button: one press latches the request for TUNE_MS, holding the finger on it changes nothing
        if (key[1].justReleased()) { drawKeyB1(); }
      }
    }

    if (n_disp_page == 1 && key[4].justPressed()) { setAutomatic(!b_automatic); }  // MODE Button
    if (n_disp_page == 1 && key[4].justReleased()) {
      tft.setTextFont(2);
      key[4].drawButton(false, b4_txt);
    }

    if (n_disp_page <= 2 && key[3].justPressed()) {  // PAGE Button
      if (n_disp_page == 1) {
        n_disp_page = 2;
      } else {
        n_disp_page = 1;
      }
      if (n_disp_page == 1) { key[3].drawButton(true, b3_p1_txt); }
      if (n_disp_page == 2) { key[3].drawButton(true, b3_p2_txt); }
      tft_update();
    }

    if (n_disp_page == 2) {

      if (key[5].justPressed()) {  // WLAN setup button
        if (b_wifi_on) {
          netListOpen();
        } else {
          hintText = "Switch to WLAN mode first";
          hintUntil = millis() + 3000;
          tft_update();
        }
      }

      if (n_disp_page == 2 && key[6].justPressed()) {  // Bluetooth <-> WLAN, takes effect after a restart
        if (millis() < modeConfirmUntil) {
          tft.fillScreen(COLOR_BG);
          tft.setTextColor(TFT_WHITE, COLOR_BG);
          tft.drawString("Restarting...", 10, 100, 4);
          writeConfig(b_wifi_on ? "b_wifi_on=false" : "b_wifi_on=true");
          delay(800);
          ESP.restart();
        }
        modeConfirmUntil = millis() + 3000;
        tft.setTextFont(1);
        key[6].drawButton(true, "Tap again");
      }
      if (n_disp_page == 2 && modeConfirmUntil != 0 && millis() > modeConfirmUntil) {
        modeConfirmUntil = 0;
        tft.setTextFont(1);
        key[6].drawButton(false, b_wifi_on ? b7_txt_on : b7_txt_off);
      }
    }
    //getsmeter();
  }

  if (millis() - aliveMillis >= aliveintervall) {  // here an alive message will be triggered every 1000ms
    aliveMillis = millis();
    getqrg();  //Request QRG from the TRX
    sendalivemessage();
    if (n_disp_page == 2) { tft_update(); }  // keeps the connection state current
    if (n_disp_page == 1) { drawLinkStatus(false); }
  }
}

// ************************************************ SUBROUTINES ****************************************************************************
void sendalivemessage() {
  int outputstate = digitalRead(TUNE_EXT_pin);
  int tuningstate = digitalRead(TUNE_REQ_pin);
  alivemsg = String(antenna_selected) + "=" + String(b_automatic) + "=" + String(outputstate) + "=" + String(tuningstate);
  Serial.println(alivemsg);
  if (bt_active) { SerialBT.println(alivemsg); }
}

void recvFromStream(Stream& port) {  // one frame <...> shared by both ports, so the state is static
  static bool recvInProgress = false;
  static byte ndx = 0;

  while (port.available() > 0 && newData == false) {
    char rc = port.read();

    if (recvInProgress) {
      if (rc != '>') {
        receivedChars[ndx] = rc;
        ndx++;
        if (ndx >= numChars) {
          ndx = numChars - 1;
        }
      } else {
        receivedChars[ndx] = '\0';  // terminate the string
        recvInProgress = false;
        ndx = 0;
        newData = true;
      }
    } else if (rc == '<') {
      recvInProgress = true;
    }
  }
}

void recvWithStartEndMarkers() {
  recvFromStream(Serial);
  if (bt_active) recvFromStream(SerialBT);
}

void parseData() {  // split the data into its parts
  char* strtokIndx;  // this is used by strtok() as an index

  strtokIndx = strtok(tempChars, ",");  // get the first part - the string
  if (strtokIndx == NULL) return;
  strcpy(SRX_TYPE, strtokIndx);         // check which message we have received
  String CSTRING = String(SRX_TYPE);
  if (CSTRING == "QRG") {
    strtokIndx = strtok(NULL, ",");
    if (strtokIndx == NULL) return;
    RX_FREQ = atof(strtokIndx);  // convert to float
    sel_band(RX_FREQ);
    QRG = RX_FREQ;
    tft_update();
    return;
  }

  String address = CSTRING;
  strtokIndx = strtok(NULL, ",");
  String setvalue = strtokIndx;

  // WLAN from the console or the PC tool: <WIFI,ssid,password>, <NETMODE,wifi|bt>, <WIFISTATUS>
  if (address == "WIFI") {
    char* pass = strtok(NULL, "");  // the rest of the line, so a password may contain commas
    wifi_ssid = setvalue;
    wifi_pass = pass ? String(pass) : String("");
    saveWifiCreds();
    if (b_wifi_on) { wifiConnectNow(); }
    Serial.println("WLAN saved: " + wifi_ssid + (b_wifi_on ? ", connecting" : ", takes effect in WLAN mode"));
    return;
  }
  if (address == "NETMODE") {
    writeConfig(setvalue == "wifi" ? "b_wifi_on=true" : "b_wifi_on=false");
    Serial.println("Restarting in " + String(setvalue == "wifi" ? "WLAN" : "Bluetooth") + " mode");
    delay(500);
    ESP.restart();
  }
  if (address == "WIFISTATUS") {
    String s = String(b_wifi_on ? "WLAN" : "BT") + " ssid=" + wifi_ssid + " state=" + wifiStateText() + " ip=" + WiFi.localIP().toString() + " rssi=" + String(WiFi.RSSI());
    Serial.println(s);
    if (bt_active) { SerialBT.println(s); }
    return;
  }

  // Change selected antenna in case requested from application tool
  if (address == "ANTNUMBER") {
    antenna_selected = setvalue.toInt();
    sel_antenna();
  }

  // Stored settings: antenna names, antenna per band, antenna count, TRX address, tuner bits
  if (isStoredKey(address)) {
    writeConfig(address + "=" + setvalue);
    if (address == "TUNEROFF") sel_antenna();
  }

  if (address == "b_automatic") { setAutomatic(!b_automatic); }

  if (address == "TUNE" && digitalRead(TUNE_EXT_pin)) { setTuning(!tuning); }
  if (address == "TUNR") { setTuner(!tuner); }
  if (address == "sendconfig") { sendConfig(); }
  if (address == "reboot") { ESP.restart(); }
  if (address == "reset") {
    SPIFFS.remove("/config.txt");
    delay(100);
    ESP.restart();
  }

  scrollposact = scrollposact - 1;
  tft_update();
}

void createDefaultConfig() {
  Serial.println("Keine default config in SPIFFS gefunden, wird erstellt...");
  File file = SPIFFS.open("/config.txt", "a");
  if (!file) {
    Serial.println("Fehler beim Erstellen der Konfigurationsdatei");
    return;
  } else {
    Serial.println("Datei erfolgreich erstellt");
  }

  // Schreibe Standard-Konfigurationswerte in die Datei
  file.println("b_wifi_on=false");
  file.println("b_automatic=true");
  file.println("a160m=1");
  file.println("a80m=2");
  file.println("a60m=3");
  file.println("a40m=4");
  file.println("a30m=5");
  file.println("a20m=6");
  file.println("a17m=7");
  file.println("a15m=8");
  file.println("a12m=7");
  file.println("a10m=6");
  file.println("a6m=5");
  file.println("a4m=4");
  file.println("A1NAME=ANTENNA 1");
  file.println("A2NAME=ANTENNA 2");
  file.println("A3NAME=ANTENNA 3");
  file.println("A4NAME=ANTENNA 4");
  file.println("A5NAME=ANTENNA 5");
  file.println("A6NAME=ANTENNA 6");
  file.println("A7NAME=ANTENNA 7");
  file.println("A8NAME=ANTENNA 8");
  file.println("TUNEROFF=00000000");
  file.println("n_ant_max=8");
  file.println("icom_use=0");
  file.println("TRX_address=152");
  file.close();
}

void geticomdata() {
  while (Serial2.available() > 0 && newData2 == false) {
    byte currentByte = Serial2.read();

    if (currentByte == startMarker) {
      dataIndex = 0;
    } else if (currentByte == endMarker) {
      newData2 = true;
    } else {
      if (dataIndex < maxDataLength) {
        receivedData[dataIndex] = currentByte;
        dataIndex++;
      }
    }
  }
}
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

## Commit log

2026-10-09 Antenna Remote firmware: WLAN/Bluetooth, web interface, SDROxide protocol, OTA, release workflow
2026-10-09 Remote port: M <0|1> switches automatic mode
2026-10-09 A <n> selects an antenna, status carries the antenna count, WLAN power save off, a quiet client can be replaced
    [Antenna-Remote.ino]
2026-10-10 TU button in automatic mode (5 s tune request, only with external tuner flag), config written only on change, cleanup
    Tune request is dropped after 5 s and on antenna or mode change. The TU/ST button switches with the mode and is greyed out without the external tuner flag. Config values are applied directly and the 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
2026-10-11 Add PCB design (KiCad project, production files, 3D model, schematic PDF)
    Project renamed to Antenna-Remote, revision reset to 1. README documents the known buzzer issue (wrong connection, pin swap, position). .history is ignored.
    [Antenna-Remote-B_Cu.gbl, Antenna-Remote-B_Mask.gbs, Antenna-Remote-B_Paste.gbp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]
2026-10-11 README: Amplitec switches, tuner function, hardware section
2026-10-11 Add ESP32 DevKitC part (symbol, footprint, 3D model) and Amplitec D-Sub connector sheet
    The ESP32 3D model path in the board and the footprint now points into hardware/parts via KIPRJMOD instead of a local drive.
    [Antenna-Remote.kicad_pcb, ESP32-DEVKITC-32D.step]
2026-10-11 Hardware: document D-SUB antenna switch pinout, U3 is the TBD62783A source driver
    Pin assignment of J1 follows the Amplitec RSW(4)(6)8A1R plan (positive switching, common ground on pin 3). U3 value and datasheet in schematic, board, netlist, BOM csv and BOM.xlsx changed from ULN2803A to the TBD62783A the schematic actually uses. Buzzer note names GPIO 34.
2026-10-11 v1.4.0: selectable frequency source (CI-V, rigctld, SDROxide), band limits, RX/TX and SWR display, TX protection, two-column antenna buttons
